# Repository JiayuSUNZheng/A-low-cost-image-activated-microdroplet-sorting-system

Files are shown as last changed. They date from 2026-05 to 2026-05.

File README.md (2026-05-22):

# Image-activated-droplet-sorter

Publicly available hardware and software resources for building a label-free,
image-activated microfluidic droplet sorting system for academic and
non-commercial research use.

The sorter uses a camera to image droplets in a microfluidic chip, a
YOLOv5s/TensorRT detector to classify each droplet, a virtual gate to decide
when a target droplet should be triggered, and an Arduino-controlled
high-voltage pulse generator to actuate selected droplets by dielectrophoresis.

System design

## What This Project Builds

This repository is intended to let another lab reproduce the complete sorting
system:

- microfluidic sorting chip with liquid-metal electrodes
- microscope-mounted camera imaging the droplet channel
- Windows GPU workstation running real-time YOLO/TensorRT inference
- Arduino firmware that converts serial commands into timed trigger pulses
- low-cost high-voltage pulse generator for electrode actuation
- training and dataset preparation tools for adapting the detector

The demonstrated configuration targets single-cell droplet sorting with three
classes:

- `0`: empty droplet
- `1`: single-cell droplet
- `2`: multi-cell droplet

## Repository Layout

```text
image-activated-droplet-sorter/
├── software/      Real-time sorter and dataset preparation tools
├── firmware/      Arduino trigger sketches
├── models/        YOLOv5s and TensorRT model artifacts
├── hardware/      Chip, holder, and high-voltage generator resources
├── docs/          Reproduction, setup, tuning, and safety guides
└── media/         Figures and demo videos
```

## Reproduction Path

1. Read `docs/safety.md` before handling the high-voltage generator.
2. Fabricate or order the chip using `hardware/microfluidic_chip/`.
3. Print or machine the holders in `hardware/holders/`.
4. Assemble the high-voltage trigger chain from
   `hardware/high_voltage_generator/`.
5. Install the Windows software environment with `docs/software_setup.md`.
6. Upload the Arduino firmware from `firmware/`.
7. Run camera, serial, and model dry runs with high voltage disconnected.
8. Tune ROI, virtual-gate position, delay bins, voltage, and flow rates.
9. Enable high voltage only after all dry-run checks pass.

## Key Demonstration Parameters

These values are starting points, not universal settings. Re-tune them for your
camera, magnification, chip, droplet speed, and channel geometry.

| Subsystem | Starting value |
| --- | --- |
| Camera | 120 FPS target acquisition |
| Runtime frame | 1280 x 640 every 10 ms |
| Detector | YOLOv5s with TensorRT runtime |
| ROI crop | 160 px high; configurable width and x/y offset |
| Model input | 160 x 160 training crops |
| Inference target | less than 5 ms per input image |
| Sorting workflow | up to 100 Hz in the demonstrated setup |
| Actuation pulse | approximately 1.2 kV for 4 ms |
| Droplet actuation delay | about 120 ms in the demonstrated setup |
| Main channel width | 145 um |
| Typical droplet diameter | about 40 um |
| Typical droplet interval | about 100 um |
| Electrode width/gap | 20 um / 20 um |
| Positive electrode protrusion | 20 um |
| Demonstration accuracy | 96.4% after tuning |

Example flow-rate starting points:

- cell suspension: 0.17 uL/min
- continuous oil phase: 2.8 uL/min
- spacing oil: 0.4 uL/min
- droplet reinjection: 2.97 uL/min

## Quick Start

Install Python dependencies on the Windows GPU workstation:

```powershell
pip install -r software/requirements-windows.txt
```

Run the real-time sorter:

```powershell
python software/realtime_sorting/sort_with_tensorrt.py --serial-port COM5 --camera-index 0
```

Common parameters:

```powershell
python software/realtime_sorting/sort_with_tensorrt.py `
  --serial-port COM5 `
  --camera-index 0 `
  --frame-roi-start-x 260 `
  --frame-roi-start-y 230 `
  --frame-roi-width 640 `
  --gate-position 290 `
  --threshold 50 `
  --confidence 0.88
```

See `docs/software_setup.md` and `software/realtime_sorting/README.md` for
details.

## Main Resources

- Chip design: `hardware/microfluidic_chip/droplet_sorting_chip.dwg`
- Camera and amplifier holders: `hardware/holders/`
- High-voltage generator notes: `hardware/high_voltage_generator/`
- Real-time Python sorter: `software/realtime_sorting/`
- Arduino firmware: `firmware/`
- Dataset tools: `software/dataset_tools/`
- Model artifacts: `models/`
- Demo video: `media/videos/sorting_process_demo.mp4`

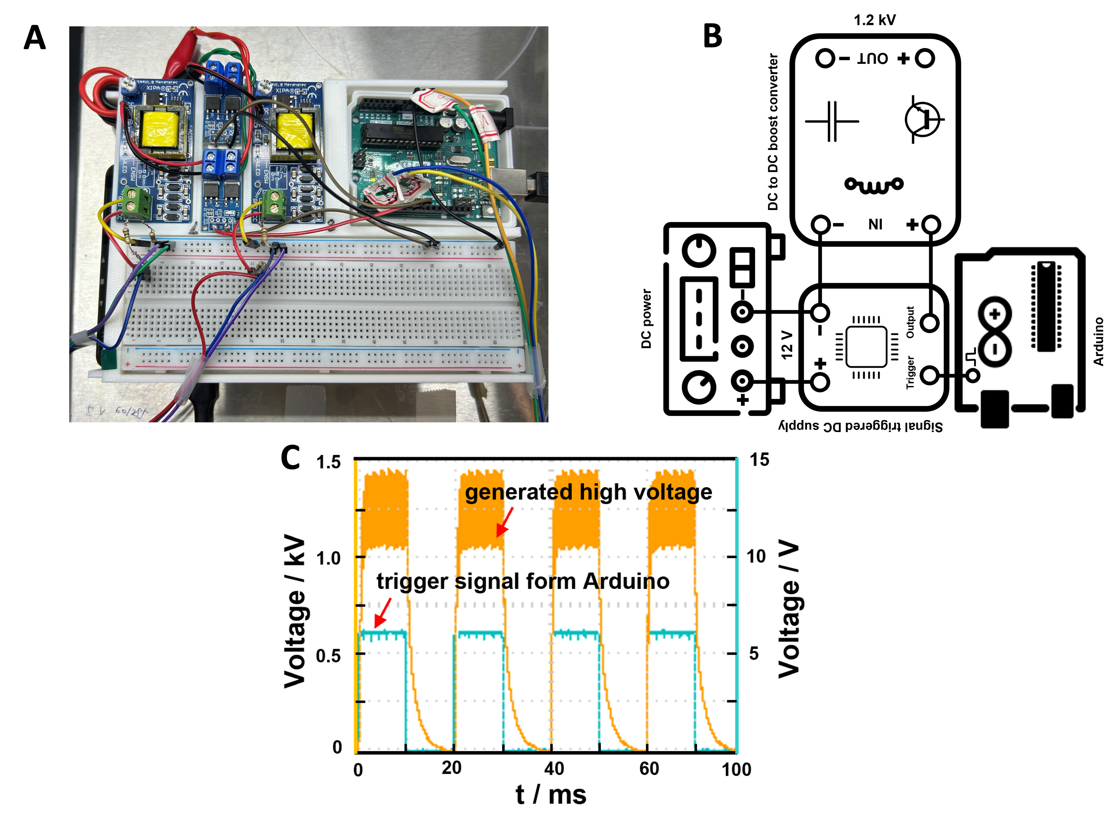
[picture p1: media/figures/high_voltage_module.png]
High-voltage module


## Documentation

- `docs/system_overview.md`: architecture, data flow, and command protocol
- `docs/hardware_setup.md`: chip, fluidics, imaging, and high-voltage assembly
- `docs/software_setup.md`: Windows, Python, TensorRT, camera, and serial setup
- `docs/operation_protocol.md`: dry run, tuning, sorting, and collection steps
- `docs/data_and_model_training.md`: dataset preparation and YOLO training
- `docs/droplet_collection_and_reinjection.md`: off-chip collection workflow
- `docs/model_evaluation.md`: detection metrics and acceptance checks
- `docs/troubleshooting.md`: common failure modes and fixes
- `docs/safety.md`: electrical, optical, fluidic, and biological safety

## Safety Notice

This project uses kilovolt-level pulses and conductive liquid paths near
microfluidic devices. Use trained personnel, insulated wiring, enclosed
high-voltage modules, current limiting, grounding, interlocks or emergency
shutoff, and an oscilloscope-verified dummy load before connecting the chip.

This is a research-use system. It is not a clinical device, consumer product,
or turnkey instrument.

## License

This repository is available under an academic and non-commercial research
license. You may use, copy, modify, fabricate, and redistribute the materials
for academic, educational, or other non-commercial research purposes only.

Commercial use is not permitted without prior written permission from the
copyright holders. This includes paid services, contract research, consulting,
commercial product development, internal commercial R&D, manufacturing for
sale, and integration into commercial instruments or workflows.

See `LICENSE`, `LICENSE-HARDWARE`, and `LICENSE-DATA` for details.

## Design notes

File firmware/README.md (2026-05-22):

# Firmware

Arduino sketches convert one-byte serial commands from the Python sorter into
timed output pulses for the high-voltage trigger driver.

## Sketches

- `arduino_one_class_sorting/`: one output pin for one target class.
- `arduino_two_class_sorting/`: separate output pins for class-1 and class-2
  target droplets.

Default settings:

- serial baud rate: 9600
- output pulse duration: 4 ms
- class-1 output pin: 8
- class-2 output pin: 9 in the two-class sketch

Always test Arduino output pins with an oscilloscope before connecting the
high-voltage trigger driver.

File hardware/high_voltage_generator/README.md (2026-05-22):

# High-Voltage Generator

The high-voltage generator receives a TTL-level trigger from Arduino and applies
a short pulse to the chip electrodes.

Signal chain:

```text
Arduino digital output -> triggered driver module
  -> DC-DC boost converter -> chip electrodes
```

Starting point for reproduction:

- Arduino serial baud rate: 9600
- Arduino output pulse duration: 4 ms
- high-voltage pulse amplitude: about 1.2 kV
- desired voltage decay: below the actuation threshold before the next sorting
  event

The available BOM is intentionally minimal. It identifies the major modules but
does not replace electrical design review, enclosure design, grounding, current
limiting, or lab safety approval.

See:

- `minimal_bom.md`
- `source_bom.docx`
- `docs/safety.md`
- `docs/hardware_setup.md`

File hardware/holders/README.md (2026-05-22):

# Holders

3D printable holder designs:

- `camera_holder.stl`
- `amplifier_holder.stl`

Check dimensions against the actual microscope, camera, and high-voltage module
assembly before printing or machining.

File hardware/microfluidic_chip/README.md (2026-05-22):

# Microfluidic Sorting Chip

`droplet_sorting_chip.dwg` is the AutoCAD design file for the sorting chip.

The chip supports:

- upstream droplet generation
- droplet reinjection
- spacing-oil control before the sorting junction
- a three-electrode dielectrophoretic actuation region
- sorted and waste outlets

Key starting geometry:

- main channel width: 145 um
- typical droplet diameter: about 40 um
- typical droplet interval: about 100 um
- electrode width: 20 um
- electrode gap: 20 um
- positive electrode protrusion: 20 um

Recommended fabrication workflow:

1. Fabricate a mold from the channel design.
2. Cast and cure PDMS.
3. Punch inlets and outlets.
4. Bond PDMS to glass.
5. Fill electrode channels with liquid metal.
6. Coat fluidic channels with hydrophobic surface modifier.
7. Inspect the sorting junction and electrode region under the microscope.

Confirm actual channel dimensions after fabrication because shrinkage, mold
height, bonding pressure, and surface treatment can change droplet behavior.

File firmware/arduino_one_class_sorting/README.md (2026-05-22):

# Arduino One-Class Sorting

Use this sketch when a single droplet class should trigger one high-voltage
output path.

Default behavior:

- output pin: 8
- serial baud rate: 9600
- output pulse duration: 4 ms
- commands: `0`, `1`, `2`, `3`

The commands encode coarse timing bins around the virtual gate. Tune the delay
values in the sketch after measuring actual camera-to-electrode timing.

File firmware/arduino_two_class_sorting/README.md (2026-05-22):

# Arduino Two-Class Sorting

Use this sketch when class-1 and class-2 droplets should drive separate trigger
outputs.

Default pins:

- class 1: pin 8
- class 2: pin 9

Command mapping:

| Command | Class | Output pin |
| --- | --- | --- |
| `0` to `3` | class 1 | 8 |
| `4` to `7` | class 2 | 9 |

The commands also encode coarse timing bins around the virtual gate. Tune the
delay values in the sketch after measuring actual camera-to-electrode timing.

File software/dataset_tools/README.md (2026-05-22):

# Dataset Tools

Utilities used during dataset preparation.

Extract frames from a video:

```powershell
python video_to_images.py input.mp4 frames --every 1
```

Crop fixed-size training images:

```powershell
python crop_images.py frames cropped --x 300 --y 100 --size 160
```

Use interactive ROI selection:

```powershell
python crop_images.py frames cropped --interactive
```

In interactive mode, use `W`, `A`, `S`, `D` to move the ROI, `SPACE` to save a
crop, and `N` to advance to the next image.

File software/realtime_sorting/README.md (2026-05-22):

# Real-Time Sorting Software

`sort_with_tensorrt.py` is the main runtime for live image-activated sorting.
It captures DirectShow frames, crops the droplet ROI, runs TensorRT inference,
draws the detection overlay, and sends serial commands to Arduino.

## Run

```powershell
python software/realtime_sorting/sort_with_tensorrt.py --serial-port COM5 --camera-index 0
```

## Important Parameters

- `--serial-port`: Arduino COM port.
- `--baud-rate`: serial baud rate, default `9600`.
- `--camera-index`: DirectShow camera index.
- `--capture-interval`: frame grab interval, default `0.010` s.
- `--frame-roi-start-x`: ROI x start in the camera frame.
- `--frame-roi-start-y`: ROI y start in the camera frame.
- `--frame-roi-width`: ROI width.
- `--gate-position`: virtual-gate x-position inside the ROI.
- `--threshold`: width of trigger bins around the virtual gate.
- `--confidence`: minimum detection confidence for triggering.
- `--model-path`: TensorRT engine path.
- `--dll-path`: inference DLL path.

Default model paths point to:

```text
models/best160-1.engine
models/best160-1.dll
```

## Dry Run Checklist

Run with the high-voltage module disconnected.

1. Confirm the camera frame appears.
2. Confirm the ROI contains droplets before the sorting junction.
3. Confirm bounding boxes are drawn on droplets.
4. Confirm class labels match visual droplet contents.
5. Confirm Arduino pins pulse only for target classes.
6. Confirm each droplet triggers once at the virtual gate.

## Tuning Sequence

1. Tune ROI x/y/width until droplets are fully visible.
2. Tune `--confidence` to reduce false triggers.
3. Tune `--gate-position` so commands are sent early enough for actuation.
4. Tune `--threshold` to avoid repeated commands.
5. Tune Arduino delay values while watching oscilloscope pulses.
6. Connect high voltage only after dry-run behavior is stable.

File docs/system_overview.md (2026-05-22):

# System Overview

The sorter is a closed-loop system that combines imaging, object detection,
timing logic, and high-voltage dielectrophoretic actuation.

## Subsystems

1. Microfluidic chip
   - Generates or receives droplets.
   - Spaces droplets before they reach the sorting junction.
   - Uses liquid-metal electrodes near the sorting junction.
   - Routes non-target droplets to the waste outlet and target droplets to the
     sorted outlet.

2. Imaging path
   - A high-speed camera is mounted on a microscope.
   - The runtime target is 120 FPS acquisition.
   - The demonstrated runtime frame size is 1280 x 640 every 10 ms.
   - The Python runtime crops a configurable ROI before inference.

3. Detection path
   - YOLOv5s detects droplet classes from the ROI.
   - TensorRT is used for low-latency inference.
   - The training crop size is 160 x 160.
   - The demonstrated target is less than 5 ms inference per image.

4. Trigger path
   - Python computes each detected droplet center.
   - The x-center is compared with a virtual gate.
   - If the droplet is a target class and lies inside a trigger bin, Python
     sends a one-byte serial command to Arduino.
   - Arduino converts that command into a delayed TTL-level pulse.

5. Actuation path
   - Arduino triggers a switching/driver stage.
   - The driver triggers the DC-DC high-voltage output.
   - The demonstrated actuation pulse is about 1.2 kV for 4 ms.
   - The electric field pulls the target droplet toward the sorted outlet.

## Data Flow

```text
camera frame
  -> crop ROI
  -> YOLOv5s/TensorRT detections
  -> class + confidence + bounding-box center
  -> virtual gate / trigger-bin decision
  -> serial command
  -> Arduino delay and output pulse
  -> high-voltage pulse
  -> droplet displacement at sorting junction
```

## Virtual Gate

The virtual gate is an x-position inside the ROI. It prevents repeated commands
for the same droplet and gives the system a timing reference before the droplet
reaches the electrodes.

Default runtime settings in `software/realtime_sorting/sort_with_tensorrt.py`:

- `--gate-position 290`
- `--threshold 50`
- `--droplet-distance 150`
- `--capture-interval 0.010`

The trigger region is divided into four bins around the gate. Each bin maps to
a different Arduino command so that the firmware can compensate timing.

## Arduino Command Protocol

The two-class runtime uses single ASCII byte commands:

| Command | Droplet class | Gate bin | Default Arduino delay |
| --- | --- | --- | --- |
| `0` | class 1 | far right of gate | 1 ms |
| `1` | class 1 | near right of gate | 1 ms |
| `2` | class 1 | near left of gate | 1.5 ms |
| `3` | class 1 | far left of gate | 1.5 ms |
| `4` | class 2 | far right of gate | 1 ms |
| `5` | class 2 | near right of gate | 1 ms |
| `6` | class 2 | near left of gate | 1.5 ms |
| `7` | class 2 | far left of gate | 1.5 ms |

Default output pins:

- class 1: Arduino digital pin 8
- class 2: Arduino digital pin 9

The firmware pulse duration is 4 ms. Adjust firmware delay values only after a
camera/serial dry run confirms that detections and command timing are stable.

## Performance Targets

- Detection and decision loop: up to 100 Hz in the demonstrated setup.
- Detector latency target: less than 5 ms per input image.
- Demonstration sorting accuracy after tuning: 96.4%.

These are setup-dependent targets. Revalidate them after any change in camera,
magnification, chip, flow rate, GPU, TensorRT version, or high-voltage module.

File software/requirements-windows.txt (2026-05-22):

opencv-python==4.5.*
numpy
pyserial
pygrabber
PyQt5
imutils
torch==1.11.*

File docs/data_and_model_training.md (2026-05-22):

# Data And Model Training

The detector can be retrained for different chips, magnifications, cell types,
droplet sizes, or target classes. The provided model uses three droplet classes:

- `0`: empty droplet
- `1`: single-cell droplet
- `2`: multi-cell droplet

## Data Collection

1. Record videos of droplets flowing through the imaging region.
2. Include empty, single-cell, and multi-cell droplets.
3. Record under illumination and focus conditions similar to sorting operation.
4. Avoid motion blur by matching exposure time to droplet speed.
5. Capture enough background variation to make the model robust to small
   changes in chip position and lighting.

## Frame Extraction

Use the frame extraction utility:

```powershell
python software/dataset_tools/video_to_images.py input.mp4 frames --every 1
```

Use `--every N` to save fewer frames when adjacent frames are too similar.

## Image Cropping

Crop droplet regions to square training images:

```powershell
python software/dataset_tools/crop_images.py frames cropped --x 300 --y 100 --size 160
```

Interactive mode:

```powershell
python software/dataset_tools/crop_images.py frames cropped --interactive
```

Interactive keys:

- `W`, `A`, `S`, `D`: move the crop region
- `SPACE`: save a crop
- `N`: advance to the next image

The demonstrated model used 160 x 160 training images and 320 labeled images.
More images are recommended when changing cells, optics, illumination, or chip
geometry.

## Labeling

Use LabelImg or another YOLO-format annotation tool.

Label every visible droplet in each crop:

- class `0`: droplet with no cell
- class `1`: droplet with one cell
- class `2`: droplet with two or more cells

Recommended checks:

- Verify that class indices match the runtime expectation.
- Verify bounding boxes cover the droplet body and visible cell content.
- Split images into train/validation sets from different video segments.
- Do not use nearly identical adjacent frames in both train and validation.

## YOLOv5s Training Parameters

Starting parameters used for the provided detector:

- model family: YOLOv5s
- image size: 160 x 160
- labeled images: 320
- batch size: 126
- epochs: 500
- training platform: Google Colab or equivalent GPU workstation

Example class configuration:

```yaml
nc: 3
names: ["0", "1", "2"]
```

## Runtime Export

The real-time sorter uses TensorRT for inference. A typical workflow is:

1. Train YOLOv5s and export PyTorch weights.
2. Validate detection accuracy on held-out images.
3. Export to ONNX or TensorRT using a version compatible with the deployment
   workstation.
4. Place the runtime artifacts in `models/`.
5. Update checksums in `models/checksums.txt`.
6. Run the sorter with high voltage disconnected and verify overlays.

Rebuild the TensorRT engine whenever CUDA, TensorRT, GPU model, or driver
versions change.

## Acceptance Criteria

Before using a new model for high-voltage sorting:

- detection overlay follows droplets frame by frame
- empty, single-cell, and multi-cell classes are visually correct
- confidence threshold rejects low-quality detections
- false positives in the virtual-gate region are rare
- runtime inference stays below the required latency for the chosen flow speed

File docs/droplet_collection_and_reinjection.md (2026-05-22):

# Droplet Collection And Reinjection

The sorter can process droplets generated upstream on the same chip or droplets
collected off-chip and reinjected later.

## Off-Chip Collection

Use a collection module with three tubing connections:

- left tubing: connected to a syringe
- middle tubing: inlet from the droplet generation chip during collection
- right tubing: outlet to the sorting chip during reinjection

During collection, connect the middle tubing to the outlet of the droplet
generation chip and collect emulsion into the module.

## Reinjection

1. Connect the collection module outlet to the sorting chip reinjection inlet.
2. Start reinjection at about 2.97 uL/min.
3. Start spacing oil at about 0.4 uL/min.
4. Watch droplets enter the main channel.
5. Increase or decrease spacing oil until droplets are separated before the
   sorting junction.

The goal is to keep adjacent droplets far enough apart that the actuation pulse
does not disturb droplets immediately before or after the target droplet.

## Tuning Tips

- If droplets arrive as dense trains, increase spacing oil or reduce reinjection
  rate.
- If droplets break or merge, reduce pressure changes and check surfactant
  concentration.
- If droplets arrive off-center, inspect inlet geometry and tubing alignment.
- If reinjected droplets are difficult to classify, retrain the detector using
  reinjection videos.

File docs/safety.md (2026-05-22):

# Safety

This system combines high voltage, liquids, microscopy hardware, pressure-driven
fluidics, and biological samples. Build and operate it only with appropriate
training and local lab approval.

## High Voltage

The actuation module can generate kilovolt-level pulses. Treat every electrode,
wire, connector, and liquid path connected to the module as hazardous.

Minimum precautions:

- use a fully enclosed high-voltage section
- use insulated connectors and strain relief
- add current limiting where possible
- add a clearly marked emergency shutoff
- keep one hand away from the setup during energized measurements
- verify output using a rated high-voltage probe and oscilloscope
- discharge the output before touching the chip or wiring
- never adjust tubing or electrodes while the module is enabled

Do not connect the chip until the high-voltage pulse has been verified on a
dummy load.

## Liquid And Electrical Paths

The chip contains conductive liquid-metal electrodes and liquid samples. Leaks
can create unintended conductive paths.

Before operation:

- inspect the chip for leaks and electrode-channel failures
- keep fluidic tubing mechanically secured
- keep high-voltage wiring physically separated from pump and camera cables
- place absorbent material away from high-voltage terminals
- stop immediately if bubbles, leaks, arcing, or unusual noise appear

## Microscope And Camera

Follow microscope illumination safety rules. Avoid eye exposure to intense light
sources. Secure the camera and printed holders so they cannot fall onto the chip
or stage.

## Biological Samples

Handle cells, media, oil, surfactants, and waste according to local biosafety
and chemical safety procedures.

Recommended practices:

- label all syringes and waste lines
- collect sorted and waste droplets in closed containers
- decontaminate or dispose of chips and tubing after use
- prevent aerosols and spills during disconnection

## Operational Boundaries

This is a research-use system. It is not a clinical device, consumer product,
or turnkey instrument. Every lab must validate electrical safety, sorting
accuracy, and sample compatibility before use.

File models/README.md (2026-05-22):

# Models

This directory contains the trained YOLOv5s/TensorRT artifacts used by the
real-time sorter.

- `best160-1.pt`: PyTorch YOLOv5s weights.
- `best160-1.engine`: TensorRT engine used by the real-time sorter.
- `best160-1.dll`: Windows x86-64 TensorRT inference wrapper used by
  `software/realtime_sorting/python_trt.py`.

The TensorRT engine is platform-specific. Rebuild it if the CUDA, TensorRT,
GPU, or driver environment differs from the original Windows 11 workstation.

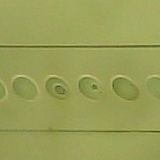
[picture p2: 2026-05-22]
media/figures/example_detection_input.jpg

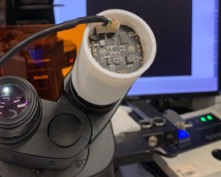
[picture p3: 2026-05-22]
media/figures/CCD_on_microscope_eye_piece.jpg

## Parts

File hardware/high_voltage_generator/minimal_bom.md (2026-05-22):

# Minimal BOM

This is a minimal component list for reproducing the triggerable high-voltage
module. It is not a complete procurement list and does not define the final
electrical safety design.

- Arduino-compatible MCU
- DC-DC high-voltage boost converter
- Triggered switching/driver module
- DC power supply for the low-voltage side
- Breadboard or custom PCB
- Resistors and jumper wires
- Insulated high-voltage wiring and connectors
- Enclosure and strain relief
- Emergency shutoff or accessible power disconnect

Verify component ratings and isolation distances before operation.

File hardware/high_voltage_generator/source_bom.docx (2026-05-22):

High-Voltage Trigger Generator Assembly Guide

For the image-activated droplet sorting system

High-voltage warning: This module can generate kilovolt-level pulses. Build, test, and operate it only with proper insulation, enclosure, current limiting, grounding, discharge procedures, and trained supervision.

# 1. Purpose And System Role

The high-voltage trigger generator converts a low-voltage pulse into a short high-voltage pulse applied to the microfluidic chip electrodes. The pulse creates dielectrophoretic force that deflects target droplets into the sorted outlet.

Signal chain: Python sorting command -> Arduino digital output -> trigger driver -> DC-DC high-voltage boost converter -> chip electrodes.

# 2. Target Electrical Behavior

Parameter | Target / Starting Value | Notes
Arduino serial rate | 9600 baud | Must match the Python runtime and firmware.
Arduino output pulse | 4 ms | Default firmware pulse width; verify on pins 8/9 before connecting the driver.
Low-voltage trigger | TTL-level digital output | Use only the Arduino side on breadboards; keep high-voltage wiring separate.
High-voltage pulse | about 1.2 kV | Starting actuation voltage for the demonstrated chip and droplets.
Pulse repetition target | up to 100 Hz workflow | The high-voltage output must decay below the actuation threshold before the next event.
Observed timing offset | about 120 ms | Setup-dependent delay between image trigger and droplet deflection; recalibrate for every build.

# 3. Minimal Bill Of Materials

Subsystem | Item | Function | Selection Notes | Qty
Control | Arduino-compatible MCU | Receives USB serial commands and generates timed digital pulses. | Use a board with stable USB serial and 5 V or 3.3 V logic compatible with the trigger driver. | 1
Host interface | USB cable | Connects the workstation to Arduino. | Use a shielded, mechanically stable cable to avoid intermittent serial disconnects. | 1
Low-voltage power | DC supply | Powers the trigger driver and/or boost converter input. | The demonstrated design uses a 12 V pulse into the boost stage. Choose current rating based on converter demand. | 1
Triggering | Signal-triggered driver module | Switches the low-voltage input to the DC-DC boost converter when Arduino pulses. | Must accept Arduino logic-level input and switch quickly and repeatably. | 1 per output path
High-voltage generation | DC-DC boost converter | Generates the kV-level pulse for dielectrophoretic actuation. | Target about 1.2 kV output; select a module with suitable isolation, insulation, discharge behavior, and current limiting. | 1
Low-voltage prototyping | Breadboard or custom PCB | Holds Arduino-side resistors and low-voltage wiring. | Do not route kV-level signals through a solderless breadboard. | 1
Signal conditioning | Resistors / pull-downs | Stabilize trigger inputs and prevent floating states. | Select values for the driver input stage; verify idle-low behavior on an oscilloscope. | as needed
Interconnects | Jumper wires | Low-voltage connections between Arduino, driver, and supply. | Use short, strain-relieved low-voltage wiring. Keep separate from high-voltage wiring. | as needed
High-voltage wiring | Rated HV cable/connectors | Connect boost output to chip electrodes. | Use insulation rating above the maximum pulse voltage and prevent exposed conductors. | as needed
Safety enclosure | Insulated box / cover | Prevents accidental contact with energized conductors. | Include cable strain relief and labels for high-voltage terminals. | 1
Measurement | Oscilloscope + HV probe | Verifies pulse timing, amplitude, and decay. | Use a probe rated for the maximum voltage and bandwidth of the pulse. | 1 set
Discharge/safety | Bleeder/discharge path and power disconnect | Provides safe shutdown and reduces residual charge. | Design according to local electrical safety rules and measured converter behavior. | 1 set

# 4. Arduino Output Mapping

The two-class firmware uses pin 8 for class-1 droplets and pin 9 for class-2 droplets. Commands are one ASCII character sent by the Python virtual-gate logic.

Command | Droplet Class | Output Pin | Default Delay Bin
0 | Class 1 | 8 | near-gate bin, 1.0 ms delay
1 | Class 1 | 8 | near-gate bin, 1.0 ms delay
2 | Class 1 | 8 | late bin, 1.5 ms delay
3 | Class 1 | 8 | late bin, 1.5 ms delay
4 | Class 2 | 9 | near-gate bin, 1.0 ms delay
5 | Class 2 | 9 | near-gate bin, 1.0 ms delay
6 | Class 2 | 9 | late bin, 1.5 ms delay
7 | Class 2 | 9 | late bin, 1.5 ms delay

# 5. Assembly Notes

1. Keep all Arduino, USB, and trigger-driver logic wiring physically separated from high-voltage wiring.
2. Use the breadboard only for low-voltage prototyping. Move repeated-use builds to a secured PCB or terminal block.
3. Mount the boost converter and high-voltage output in an insulated enclosure before operation.
4. Label low-voltage input, Arduino trigger input, high-voltage output, ground return, and discharge points.
5. Add strain relief to wires connected to the microscope stage or chip holder.
6. Confirm that the high-voltage ground/reference is connected exactly as intended for the electrode design.

# 6. Bench Verification Before Connecting The Chip

7. Upload the Arduino sketch and disconnect the high-voltage stage.
8. Send test commands from the workstation and measure Arduino output pins with an oscilloscope.
9. Confirm each output pulse is 4 ms and returns cleanly to LOW.
10. Connect the trigger driver with the high-voltage output still disconnected from the chip.
11. Connect the high-voltage output to a rated dummy load and measure with a high-voltage probe.
12. Confirm pulse amplitude, pulse width, voltage decay, and absence of unintended retriggering.
13. Power down and discharge the module before changing wiring.

# 7. Integration With The Sorting Chip

Connect the positive high-voltage output to the positive liquid-metal electrode and connect the ground electrodes to the generator reference/ground as required by the electrode layout. Verify this wiring with power off before enabling the high-voltage module.

Start sorting at low droplet density. Increase flow speed only after target droplets consistently enter the sorted outlet and neighboring droplets are not disturbed.

# 8. Acceptance Checklist

- Arduino serial communication is stable at 9600 baud.
- Output pins pulse only when the Python sorter sends target commands.
- Trigger-driver input is not floating when idle.
- High-voltage output reaches the required pulse amplitude and decays before the next event.
- No exposed high-voltage conductor is accessible during operation.
- The chip sorts test droplets before biological samples are introduced.
- Voltage, pulse width, ROI, virtual gate, flow rates, and firmware delay values are recorded for each run.

# 9. Maintenance And Version Control

- Record module part numbers, converter settings, and measured output waveforms for each build.
- Recheck pulse behavior after replacing any driver, converter, Arduino board, or power supply.
- Revalidate sorting after changing chip geometry, tubing, microscope magnification, or droplet speed.
- Keep a photo of the assembled wiring with labels for future troubleshooting.

# Appendix: Reference Assembly Image


Reference image of the low-cost high-voltage trigger module and representative trigger/output waveform.

High-Voltage Trigger Generator BOM and Assembly Guide

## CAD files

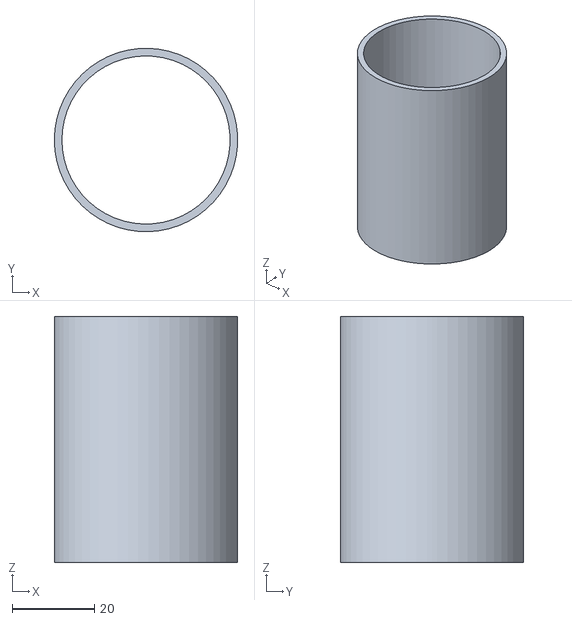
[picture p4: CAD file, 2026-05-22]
hardware/holders/camera_holder.stl
44.7 x 44.7 x 60.0

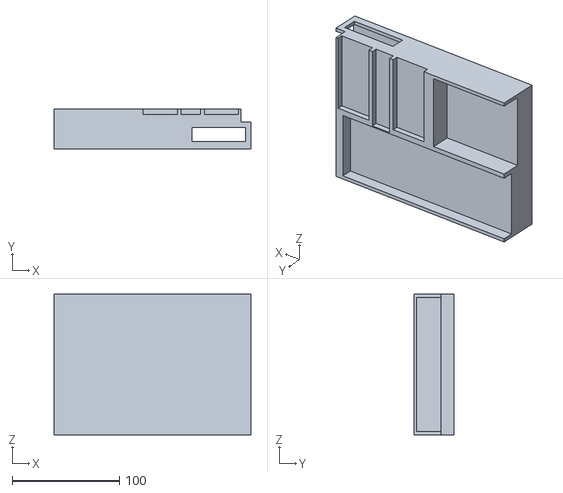
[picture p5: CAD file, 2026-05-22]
hardware/holders/amplifier_holder.stl
183.5 x 37.0 x 131.0

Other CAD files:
hardware/microfluidic_chip/droplet_sorting_chip.dwg

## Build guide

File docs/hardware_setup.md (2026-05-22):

# Hardware Setup

This guide describes the physical build needed to reproduce the droplet sorting
system. Dimensions and flow rates below are starting points for the provided
chip design and demonstration setup.

## Required Hardware

- Microfluidic sorting chip fabricated from `hardware/microfluidic_chip/`.
- Microscope with enough working distance for tubing, chip, and electrodes.
- High-speed camera capable of about 120 FPS acquisition.
- Windows GPU workstation.
- Arduino-compatible MCU.
- Triggered high-voltage pulse generator.
- DC-DC boost converter capable of about 1.2 kV output.
- Breadboard or custom PCB for low-voltage trigger wiring.
- Syringe pumps for sample, continuous oil, spacing oil, and reinjection.
- PTFE or compatible tubing, fittings, syringes, and collection tubing.
- 3D printed or machined holders from `hardware/holders/`.
- Oscilloscope and high-voltage probe for verification.

## Chip And Electrode Geometry

The chip design is provided as:

```text
hardware/microfluidic_chip/droplet_sorting_chip.dwg
```

Starting geometry values:

- main channel width: 145 um
- typical droplet diameter: about 40 um
- typical droplet interval: about 100 um
- electrode width: 20 um
- electrode gap: 20 um
- positive electrode protrusion: 20 um

The sorting junction uses one positive electrode between two ground electrodes.
Target droplets are pulled toward the sorted outlet when the high-voltage pulse
is applied.

## Chip Fabrication

1. Fabricate the channel mold using the DWG design and the lab's standard
   soft-lithography workflow.
2. Cast PDMS, cure, peel, and punch inlets/outlets.
3. Bond the PDMS device to a glass slide.
4. Fill the one-port-open electrode channels with liquid metal.
5. Before operation, coat fluidic channels with a hydrophobic surface modifier.
6. Inspect all channels and electrodes under the microscope before connecting
   pressure or voltage.

## Fluidic Connections

The chip supports both upstream droplet generation and reinjection.

In-chip generation starting points:

- cell suspension: 0.17 uL/min
- continuous oil phase: 2.8 uL/min
- spacing oil: 0.4 uL/min

Reinjection starting points:

- collected droplet reinjection: 2.97 uL/min
- spacing oil: 0.4 uL/min

Use spacing oil to increase distance between adjacent droplets before the
sorting junction. Insufficient spacing can cause the high-voltage pulse to
affect neighboring droplets.

## Imaging Setup

1. Mount the chip on the microscope.
2. Mount the high-speed camera using the provided holder or an equivalent
   rigid adapter.
3. Focus on the main channel upstream of the sorting electrodes.
4. Adjust illumination so droplets and cell contents are visible without
   saturating the image.
5. Confirm camera acquisition at the target frame rate before connecting the
   high-voltage module.

The runtime software crops a 160-pixel-high ROI from each frame. Align the ROI
so droplets are fully visible before reaching the virtual gate.

## High-Voltage Trigger Chain

Logical signal chain:

```text
Python serial command -> Arduino output pin -> trigger driver
  -> DC-DC boost converter -> chip electrodes
```

Demonstration starting point:

- high-voltage pulse amplitude: about 1.2 kV
- pulse duration: 4 ms
- observed droplet actuation delay: about 120 ms

Before connecting the chip:

1. Disconnect the chip electrodes.
2. Trigger Arduino manually or from Python.
3. Measure the Arduino pin with an oscilloscope.
4. Measure the high-voltage output with a rated high-voltage probe.
5. Confirm pulse width, amplitude, decay, and repetition behavior.
6. Only then connect the chip electrodes.

## Holders

Provided STL files:

- `hardware/holders/camera_holder.stl`
- `hardware/holders/amplifier_holder.stl`

Check dimensions against your microscope, camera body, stage, and high-voltage
module before printing. Printed parts must not expose high-voltage conductors.

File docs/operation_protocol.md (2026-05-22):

# Operation Protocol

This protocol is written for a complete system with chip, microscope, camera,
Arduino, high-voltage trigger chain, and syringe pumps assembled.

## 1. Pre-Run Inspection

1. Inspect the chip channels for dust, blocked channels, collapsed PDMS, or
   incomplete bonding.
2. Inspect liquid-metal electrodes for continuity and no leakage into fluidic
   channels.
3. Confirm all tubing is connected to the intended inlets and outlets.
4. Confirm sorted and waste outlets are connected to collection tubing.
5. Confirm the high-voltage output is disabled and discharged.

## 2. Fluidic Startup

For upstream generation:

1. Start continuous oil at about 2.8 uL/min.
2. Start spacing oil at about 0.4 uL/min.
3. Start cell suspension at about 0.17 uL/min.
4. Wait until droplets are stable and monodisperse.
5. Tune pump rates until droplet spacing is close to 100 um.

For reinjection:

1. Load collected droplets into the reinjection module.
2. Start reinjection at about 2.97 uL/min.
3. Start spacing oil at about 0.4 uL/min.
4. Tune spacing oil until adjacent droplets are separated before sorting.

## 3. Imaging Alignment

1. Focus on the main channel before the sorting junction.
2. Adjust illumination for visible droplet boundaries and cell contents.
3. Run the Python sorter with high voltage disconnected.
4. Tune ROI start x/y and ROI width until droplets are fully visible.
5. Confirm the detection overlay follows droplets without large false positives.

Example:

```powershell
python software/realtime_sorting/sort_with_tensorrt.py `
  --serial-port COM5 `
  --camera-index 0 `
  --frame-roi-start-x 260 `
  --frame-roi-start-y 230 `
  --frame-roi-width 640
```

## 4. Virtual Gate Tuning

1. Place the virtual gate upstream of the electrode center.
2. Start with `--gate-position 290` and `--threshold 50`.
3. Confirm target droplets are marked once, not repeatedly.
4. If droplets are triggered too early, move the gate downstream or increase the
   Arduino delay.
5. If droplets are triggered too late, move the gate upstream or reduce the
   Arduino delay.

The demonstrated optical setup used a virtual gate about 350 pixels upstream
from the electrode center. Recalibrate this distance for every camera/magnifier
combination.

## 5. Arduino And Pulse Dry Run

Keep high voltage disconnected from the chip.

1. Upload the selected Arduino sketch.
2. Run the Python sorter.
3. Measure Arduino output pins with an oscilloscope.
4. Confirm trigger pulses are 4 ms.
5. Confirm commands occur only when target droplets pass through the gate.
6. Confirm class-to-pin mapping if using two-class sorting.

## 6. High-Voltage Verification

With the chip still disconnected:

1. Connect Arduino output to the trigger driver.
2. Connect the high-voltage output to a rated dummy load.
3. Measure output with a high-voltage probe.
4. Confirm about 1.2 kV pulse amplitude.
5. Confirm pulse decay is fast enough for the intended sorting frequency.
6. Confirm the module does not self-trigger or latch on.

## 7. Sorting Run

1. Connect the high-voltage output to chip electrodes.
2. Start at low droplet density and conservative flow rates.
3. Enable the Python sorter.
4. Enable high voltage.
5. Observe target droplets at the sorting junction.
6. Tune voltage, gate, threshold, and delay bins until target droplets enter the
   sorted outlet while non-target droplets remain in the waste outlet.
7. Increase flow rate only after stable sorting is observed.

## 8. Collection And Shutdown

1. Collect sorted droplets from the sorted outlet.
2. Record runtime parameters, pump rates, voltage, pulse width, ROI, gate, and
   threshold.
3. Disable high voltage before stopping fluid flow.
4. Discharge high-voltage wiring.
5. Stop pumps.
6. Flush or dispose of chip and tubing according to sample safety rules.

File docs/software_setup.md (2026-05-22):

# Software Setup

The real-time sorter is designed for Windows because it uses DirectShow camera
capture and a Windows x86-64 TensorRT DLL.

## Target Workstation

Recommended starting environment:

- Windows 11, 64-bit
- NVIDIA GPU with CUDA support
- Python 3.9
- OpenCV 4.5
- PyTorch 1.11.0
- TensorRT 8.2.5.1
- Arduino IDE or Arduino CLI

The demonstrated workstation used an AMD Ryzen 7 5800H CPU, 16 GB RAM, and an
NVIDIA GTX 3060Ti 6 GB GPU.

## Python Environment

Create and activate a Python 3.9 environment, then install:

```powershell
pip install -r software/requirements-windows.txt
```

Core Python packages:

- `opencv-python`
- `numpy`
- `pyserial`
- `pygrabber`
- `PyQt5`
- `imutils`
- `torch`

TensorRT itself is installed separately from NVIDIA packages. Confirm the
TensorRT Python/runtime libraries match the GPU driver and CUDA environment.

## Model Files

Model artifacts are stored in `models/`:

- `best160-1.pt`: YOLOv5s PyTorch weights
- `best160-1.engine`: TensorRT engine
- `best160-1.dll`: Windows inference wrapper used by `python_trt.py`
- `checksums.txt`: SHA256 checksums

The `.engine` file is platform-specific. Rebuild it when changing GPU,
TensorRT, CUDA, or driver versions.

## Arduino Setup

1. Connect the Arduino by USB.
2. Open Device Manager and identify the COM port.
3. Upload one of the sketches in `firmware/`.
4. Confirm the baud rate is `9600`.
5. Keep the high-voltage module disconnected for the first serial test.

## Camera Setup

Check available DirectShow camera indices:

```powershell
python -c "from pygrabber.dshow_graph import FilterGraph; print(FilterGraph().get_input_devices())"
```

Use the index of the high-speed camera in the runtime command.

## Dry Run Command

Run without high voltage connected:

```powershell
python software/realtime_sorting/sort_with_tensorrt.py --serial-port COM5 --camera-index 0
```

If the model files are in another location:

```powershell
python software/realtime_sorting/sort_with_tensorrt.py `
  --serial-port COM5 `
  --camera-index 0 `
  --model-path C:\path\to\best160-1.engine `
  --dll-path C:\path\to\best160-1.dll
```

## Runtime Parameters

Common parameters:

- `--serial-port`: Arduino COM port.
- `--baud-rate`: default `9600`.
- `--camera-index`: DirectShow camera index.
- `--capture-interval`: default `0.010` s.
- `--frame-roi-start-x`: ROI x start.
- `--frame-roi-start-y`: ROI y start.
- `--frame-roi-width`: ROI width.
- `--gate-position`: virtual-gate x-position inside the ROI.
- `--threshold`: trigger-bin half-width around the virtual gate.
- `--confidence`: minimum detector confidence for triggering.
- `--droplet-distance`: estimated spacing between droplet centers.

Use conservative threshold and confidence values during initial tuning. Increase
sorting speed only after the detection overlay and Arduino output pulses are
stable.

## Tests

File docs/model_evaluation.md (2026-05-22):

# Model Evaluation

The detector must be evaluated before it is used to trigger high voltage.

## Detection Metrics

Use the standard object-detection metrics produced by YOLO training:

- precision
- recall
- mAP@0.5
- mAP@0.5:0.95
- confusion matrix

For sorting, false positives near the virtual gate are especially important
because they can trigger unwanted actuation.

## Visual Evaluation

Review detection overlays on videos recorded from the actual sorting setup.

Check that:

- class `0` droplets are not triggered
- class `1` droplets are detected consistently
- class `2` droplets are classified separately from class `1`
- bounding boxes are stable while droplets move through the ROI
- detections do not flicker at the virtual gate
- lighting changes do not create false droplets

## Runtime Evaluation

Measure inference time on the deployment workstation. The demonstrated target is
less than 5 ms per input image. The total detection and command loop must stay
within the droplet arrival interval.

If throughput is unstable:

- reduce ROI width
- rebuild the TensorRT engine for the target GPU
- increase confidence threshold
- reduce camera frame size if supported
- lower droplet generation or reinjection speed

## Sorting Evaluation

Run evaluation in stages:

1. camera and model overlay only
2. Arduino trigger output only
3. high-voltage output into dummy load
4. chip connected with non-biological test droplets
5. full sample sorting

Record sorted outlet composition and calculate sorting accuracy from collected
droplets. The demonstrated setup reached 96.4% after tuning.

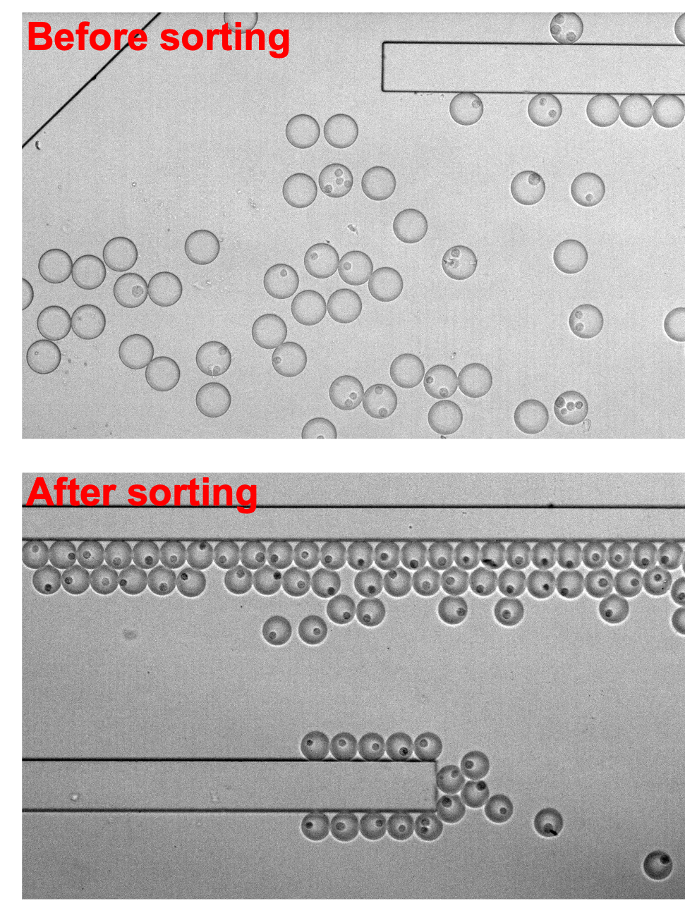
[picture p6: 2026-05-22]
media/figures/sorting_result.png

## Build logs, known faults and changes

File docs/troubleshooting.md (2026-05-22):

# Troubleshooting

## Camera Not Found

- Check Device Manager for the camera.
- Run the DirectShow device listing command in `docs/software_setup.md`.
- Try a different `--camera-index`.
- Close vendor camera software that may already hold the device.

## No Detections

- Confirm `models/best160-1.engine` and `models/best160-1.dll` exist.
- Confirm the ROI contains droplets.
- Lower `--confidence` during debugging.
- Check illumination and focus.
- Test the detector on a still image before live sorting.

## TensorRT Or DLL Error

- Confirm the DLL is Windows x86-64.
- Confirm TensorRT, CUDA, GPU driver, and engine versions are compatible.
- Rebuild the TensorRT engine on the deployment workstation.
- Check `models/checksums.txt` for file integrity.

## Serial Port Error

- Confirm the Arduino COM port.
- Close Arduino Serial Monitor or other software using the port.
- Confirm baud rate is `9600`.
- Try a simple serial test before running the full sorter.

## Arduino Pulse Missing

- Confirm the correct sketch is uploaded.
- Measure pins 8 and 9 with an oscilloscope.
- Confirm Python sends commands only when droplets pass the virtual gate.
- Confirm USB cable and board power are stable.

## False Triggering

- Increase `--confidence`.
- Narrow `--threshold`.
- Move the virtual gate to a region with clearer droplet images.
- Improve lighting uniformity.
- Retrain with more negative examples and difficult frames.

## Target Droplets Miss The Sorted Outlet

- Verify high-voltage pulse amplitude and duration.
- Tune `--gate-position` and firmware delay values.
- Reduce flow speed.
- Increase droplet spacing.
- Confirm electrode wiring polarity and ground connections.
- Check whether the droplet is centered in the channel before actuation.

## Neighbor Droplets Are Disturbed

- Increase spacing oil flow.
- Reduce droplet generation or reinjection rate.
- Shorten pulse duration only if actuation remains sufficient.
- Reduce voltage only if target droplets still sort reliably.

## Droplets Merge Or Break

- Check surfactant and oil compatibility.
- Reduce abrupt pressure changes.
- Inspect chip surface treatment.
- Check for dust or channel defects.

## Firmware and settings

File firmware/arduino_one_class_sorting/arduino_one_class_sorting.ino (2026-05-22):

const int ledPin = 8;

unsigned long previousMillis = 0;
unsigned long currentMillis = 0;
unsigned long delayMillis = 0;

const long interval = 4;  // output pulse duration in milliseconds
float delay_interval = 0.0;
int flag = 0;

char var;

void setup() {
  Serial.begin(9600);
  pinMode(ledPin, OUTPUT);
  digitalWrite(ledPin, LOW);
  var = Serial.read();
}

void loop() {
  var = Serial.read();
  currentMillis = millis();

  // Delay bins for target droplets. Commands are sent by the Python virtual gate.
  if (var == '3') {
    delayMillis = currentMillis;
    delay_interval = 1.5;
  }
  else if (var == '2') {
    delayMillis = currentMillis;
    delay_interval = 1.5;
  }
  else if (var == '1') {
    delayMillis = currentMillis;
    delay_interval = 1.0;
  }
  else if (var == '0') {
    delayMillis = currentMillis;
    delay_interval = 0.5;
  }

  if (delay_interval > 0 && currentMillis - delayMillis >= delay_interval) {
    if (flag == 0) {
      flag = 1;
      previousMillis = currentMillis;
    }
    if (currentMillis - previousMillis < interval) {
      digitalWrite(ledPin, HIGH);
    }
    else {
      digitalWrite(ledPin, LOW);
      flag = 0;
      delay_interval = 0.0;
    }
  }
}

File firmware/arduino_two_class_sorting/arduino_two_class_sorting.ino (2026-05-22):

const int oneCell = 8;
const int twoCell = 9;

unsigned long previousMillis = 0;
unsigned long currentMillis = 0;
unsigned long delayMillis = 0;

const long interval = 4;  // output pulse duration in milliseconds
float delay_interval = 0.0;
int flagOne = 0;  // 0: LOW, 1: HIGH
int flagTwo = 0;  // 0: LOW, 1: HIGH

// 1: class-1 droplet, 2: class-2 droplet, 3: no valid droplet command
int type = 3;

char var;

void setup() {
  Serial.begin(9600);
  pinMode(oneCell, OUTPUT);
  digitalWrite(oneCell, LOW);
  pinMode(twoCell, OUTPUT);
  digitalWrite(twoCell, LOW);
  var = Serial.read();
}

void loop() {
  var = Serial.read();
  currentMillis = millis();

  // Class-1 droplet delay bins. Commands are sent by the Python virtual gate.
  if (var == '3') {
    type = 1;
    delayMillis = currentMillis;
    delay_interval = 1.5;
  }
  else if (var == '2') {
    type = 1;
    delayMillis = currentMillis;
    delay_interval = 1.5;
  }
  else if (var == '1') {
    type = 1;
    delayMillis = currentMillis;
    delay_interval = 1.0;
  }
  else if (var == '0') {
    type = 1;
    delayMillis = currentMillis;
    delay_interval = 1.0;
  }

  if (type == 1 && delay_interval > 0 && currentMillis - delayMillis >= delay_interval) {
    if (flagOne == 0) {
      flagOne = 1;
      previousMillis = currentMillis;
    }
    if (flagOne == 1 && currentMillis - previousMillis < interval) {
      digitalWrite(oneCell, HIGH);
    }
    else {
      digitalWrite(oneCell, LOW);
      flagOne = 0;
      delay_interval = 0.0;
    }
  }

  // Class-2 droplet delay bins. Commands are sent by the Python virtual gate.
  if (var == '7') {
    type = 2;
    delayMillis = currentMillis;
    delay_interval = 1.5;
  }
  else if (var == '6') {
    type = 2;
    delayMillis = currentMillis;
    delay_interval = 1.5;
  }
  else if (var == '5') {
    type = 2;
    delayMillis = currentMillis;
    delay_interval = 1.0;
  }
  else if (var == '4') {
    type = 2;
    delayMillis = currentMillis;
    delay_interval = 1.0;
  }

  if (type == 2 && delay_interval > 0 && currentMillis - delayMillis >= delay_interval) {
    if (flagTwo == 0) {
      flagTwo = 1;
      previousMillis = currentMillis;
    }
    if (flagTwo == 1 && currentMillis - previousMillis < interval) {
      digitalWrite(twoCell, HIGH);
    }
    else {
      digitalWrite(twoCell, LOW);
      flagTwo = 0;
      delay_interval = 0.0;
    }
  }
}
